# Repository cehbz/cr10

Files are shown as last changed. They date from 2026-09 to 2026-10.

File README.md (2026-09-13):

# CR-10 refurbishment

Notes and firmware for a used 2017 Creality CR-10: 12 V, the original
Creality Melzi board (ATmega1284P, FT232R USB serial, no bootloader as
shipped), stock 12864 display, and an owner-added second power supply
feeding the bed through an external MOSFET module.

## Firmware

The board shipped with Creality's Marlin 1.0.0 build from October 2017. That
build has no thermal runaway protection and no `M112` handler; its published
source is at https://github.com/Creality3DPrinting/CR10-Melzi-1.1.2.

This repo builds Marlin 2.1.2.8 for it.

- `Marlin/` is the upstream Marlin repository as a submodule, pinned to the
  2.1.2.8 tag.
- `config/` is Marlin's own CR-10 example configuration
  (`config/examples/Creality/CR-10/CrealityV1` from the Configurations repo
  at `release-2.1.2.8`) with one change: `EMERGENCY_PARSER` enabled in
  `Configuration_adv.h`, so `M112` is acted on immediately rather than queued.
  Thermal protection for hotend and bed is on in the example config.
- `boot/` is the optiboot bootloader the build assumes; see `boot/README.md`.

Build (needs PlatformIO):

```
git clone --recurse-submodules --shallow-submodules <this repo>
scripts/build.sh
```

The result is `build/firmware.hex`. It uses about 97% of flash and 93% of
RAM, which is normal for Marlin 2 on this processor.

### One-time: bootloader over ISP

Because the board has no bootloader, the first flash goes through the 6-pin
ISP header next to the processor, using an FT232H breakout as the
programmer (avrdude's `ft232h` definition; the FT232H's inputs are 5 V
tolerant, so no level shifting). Pin 1 of the header has a square pad.

```
ISP header            FT232H
1 MISO  2 VCC         AD2 -> pin 1
3 SCK   4 MOSI        AD0 -> pin 3
5 RESET 6 GND         AD1 -> pin 4
                      AD3 -> pin 5
                      GND -> pin 6
```

Pin 2 stays unconnected: the printer's own supply powers the board during
programming. With the printer on and the FT232H plugged in:

```
scripts/isp.sh probe        # expect Device signature = 0x1e9705
scripts/isp.sh backup       # stock flash + EEPROM to backup/ (kept out of git)
scripts/isp.sh bootloader   # erase, fuses, optiboot
```

On macOS, avrdude may need `sudo` to claim the FT232H from Apple's FTDI
driver. After this step the display is blank until firmware is flashed.

### Flashing over USB

With the bootloader in place, every flash is over the printer's USB port:

```
scripts/flash.sh            # PORT=/dev/tty.usbserial-XXXX to override
```

Stock firmware talked at 115200 baud; so does this build. After a reflash
the EEPROM is reset, so PID and E-steps need redoing and saving with `M500`.

## Hardware findings from the checkout

Recorded here because they are the kind of thing the next owner of a
machine like this needs to know.

- Both power supplies had been trimmed off nominal: the mainboard supply to
  14.4 V and the bed supply to 10.8 V. Both reset to 12.0 V with the pot
  next to the terminal strip.
- The external bed MOSFET module was the common clone design: PC817
  optocoupler, HA210N06-marked MOSFET, and a resistor divider on the gate
  that leaves the gate at half the module's supply. On a 24 V machine that
  is 12 V and the part is fully on; on a 12 V machine it is about 6 V and
  the part runs hot. The heatsink reached 100 °C at under 7 A of bed
  current. Replaced with a module that has a transistor stage after the
  optocoupler.
- The bed wires were terminated with fork lugs pushed into the module's
  cage-clamp terminals. The lugs, not the terminals, discoloured and
  reached 140 °C. Cage clamps take ferrules.
- Stock endstops read `open` at rest and `TRIGGERED` pressed, with pullups
  and no inversion, so an unplugged switch is indistinguishable from an
  untriggered one; homing must be verified by pressing each switch by hand
  under `M119` before the first `G28`.
- The stock 1.0.0 firmware drives the bed in bang-bang mode as a 50% duty
  software PWM at about 7.6 Hz, not fully on, so any external module must
  tolerate PWM. Marlin 2 does the same.

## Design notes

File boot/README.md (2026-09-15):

# optiboot for the Melzi ATmega1284P

`optiboot_atmega1284p.hex` is the unmodified 16 MHz, 115200 baud optiboot
build from the Sanguino core:

- https://github.com/Lauszus/Sanguino/blob/master/bootloaders/optiboot/optiboot_atmega1284p.hex
- last changed in commit `60fbbcf5eaa8ee9167051877b00fb02546c1ba97`
- sha256 `83e8bcac3e177aa47b4fdbff8a5da66cb107e762a721093bb444ebcca130ea00`

The hex is linked at byte 0x1FC00, the top 1 KB of flash, so BOOTSZ has to
select a 512-word boot section based there. That makes the fuses lfuse 0xFF
(external crystal), hfuse 0xDC (BOOTSZ=10 plus BOOTRST), efuse 0xFD (brown-out
at 2.7 V), applied by `scripts/isp.sh bootloader`.

Note that Sanguino's `boards.txt` pairs this same hex with hfuse 0xDE, which
selects a 256-word section based at 0x1FE00. That matches neither where the hex
is linked nor that file's own `upload.maximum_size` of 130048, which reserves
1 KB. Burning 0xDE leaves the reset vector pointing at blank flash, so the
bootloader never runs. The Melzi bootloader guides use 0xDC, and Marlin's
`melzi_optiboot` environment reserves the same 1 KB.

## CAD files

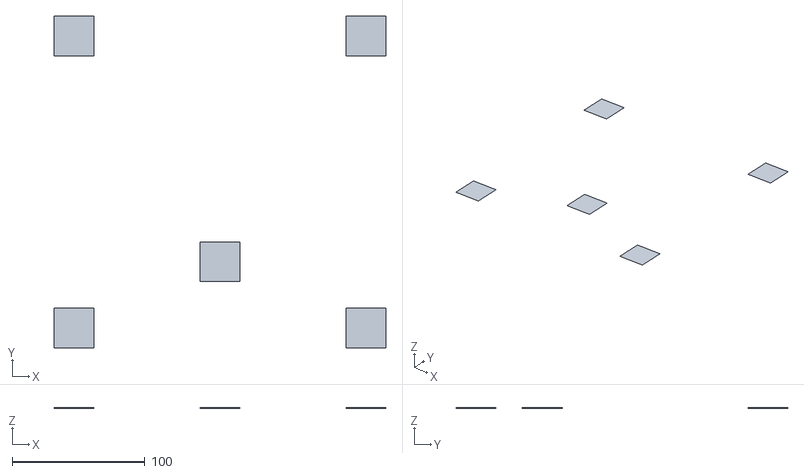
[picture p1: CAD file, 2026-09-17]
models/first_layer_test_offcentre.stl
250.0 x 250.0 x 0.2

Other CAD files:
models/first_layer_test.stl
models/rx100m6-bracket.f3d

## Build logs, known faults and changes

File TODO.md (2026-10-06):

# CR-10 — next session

Machine prints. Filament dried; the storage box sits at ~10 % RH with ~120 g of gel in a
printed tray. Background and measured values: `~/.claude/knowledge/projects/cr10.md`;
history `~/.claude/knowledge/projects/cr10/observations.md`.

## 1. Silent mid-print reboot

Desiccant-box attempt 2: the printer rebooted partway through the first layers with no LCD
message and no USB connected. Marlin shows a message and halts on a thermal fault, and
reports SD errors, so neither fits a silent reboot. Surviving: brownout (the bed's 11–17 A returns
through the negative-to-negative bond between the supplies), watchdog reset (RAM 15296 /
16384 B, a print of thousands of short moves), mains glitch. Not seen since.

If it recurs: start `picocom -b 115200 --imap lfcrlf --logfile <file>
/dev/tty.usbserial-A906UGE8` before the print (opening the port resets the board once,
harmless before a print), start the print from the LCD, leave it logging. The boot banner
after a reboot names the cause: Brown out / Watchdog / Power-Up.

## 2. Bed PSU label

Read the rating on the bed PSU when the case is open, and record it in the observations
log. It was never written down.

## 3. Bed PID tune

Still on Marlin defaults. It holds setpoint, so this is polish. `MAX_BED_POWER` is 255,
so nothing is capping bed duty.

## 4. Corner lift on a long floor

On the next PETG part with a floor of about 200 mm or more, observe whether a corner lifts
at bed 75 with the window closed and the fans off.

## 5. RX100M6 tripod bracket

Fit the print of `models/rx100m6-bracket.stl`. Dry, with the dummy battery in: the door
resting on the slope's end without pinching the cable, the door's hinge arms clearing the
boss, nothing touching the lens or LCD. When the 1/2" button-head screws and 1/4"-20 nuts
arrive: the screw's protrusion, and whether the camera turns on the screw (a lip or a pad if
it does). Design in the KB node, Enclosures for other projects.

## Considered

- Considered, not ordered: textured PEI spring steel with magnetic base, ~฿900, which is the
  right surface for PETG and would end the glass chipping.
- Considered, not started: **24 V on the bed.** The version of the second-PSU mod with a
  real payoff — heat-up in a few minutes rather than ~10, and 80 °C within reach. Two 12 V
  supplies in series into the bed only, external switch stays in the negative leg (the
  clone's PC817 input is isolated, so the stack can float). Not a drop-in: ~37 A full-on on
  this bed, so 10 AWG on the run, a 40 A-class switch (not the MOS25), `MAX_BED_POWER`
  back to ~128 or accept the inrush, and the negative-to-negative bond between the supplies
  has to go. Decide after a few prints whether the heat-up actually bothers you.
- Considered, not ordered: bed insulation mat (cork or foil-faced) under the plate. Cheap,
  no electrical risk, cuts heat-up time and holding duty. Check whether one is already
  fitted before buying.

## Standing

The full-length attended print has happened: the Benchy ran over an hour at bed 75 with
correct polarity and all four module terminations fresh, and nothing in the bed circuit ran
warm. The condition that gated unattended running is discharged. Whether to leave it running
— drying on the bed is hours of bed-only at 60 — is your call, not a rule.

**No bed thermal fuse.** Decided 2026-09-19: not going to fit one, not going to check for
one. The mitigation is attendance, and the one failure of this class that occurred — the
reversed DC input, which heated the bed whenever the machine had power, commanded or not —
was in fact caught that way. Settled; do not re-raise.

The uncommanded heating was a wiring error and is cured, demonstrated rather than assumed:
full supply across the device when commanded off, device at ambient, bed flat. One earlier
observation stays unexplained: 2026-09-11, original module, bed commanded off at 73 and read
77 then 83. That module's input polarity was never observed, so the same reversal would
account for it; the wiring was redone when it was replaced and it cannot now be tested.

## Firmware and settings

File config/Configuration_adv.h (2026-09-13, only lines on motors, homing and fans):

#define E0_AUTO_FAN_PIN -1
#define E1_AUTO_FAN_PIN -1
#define E2_AUTO_FAN_PIN -1
#define E3_AUTO_FAN_PIN -1
#define E4_AUTO_FAN_PIN -1
#define E5_AUTO_FAN_PIN -1
#define E6_AUTO_FAN_PIN -1
#define E7_AUTO_FAN_PIN -1
#define CHAMBER_AUTO_FAN_PIN -1
#define COOLER_AUTO_FAN_PIN -1
#define HOMING_BUMP_MM      { 5, 5, 2 }       // (linear=mm, rotational=°) Backoff from endstops after first bump
#define HOMING_BUMP_DIVISOR { 2, 2, 4 }       // Re-Bump Speed Divisor (Divides the Homing Feedrate)
#define QUICK_HOME                            // If G28 contains XY do a diagonal move first
#define MICROSTEP_MODES { 16, 16, 16, 16, 16, 16 } // [1,2,4,8,16]
#define ADVANCED_PAUSE_FEATURE
  #define ADVANCED_PAUSE_PURGE_FEEDRATE        3  // (mm/s) Extrude feedrate (after loading). Should be slower than load feedrate.
  #define ADVANCED_PAUSE_PURGE_LENGTH         50  // (mm) Length to extrude after loading.
  #define ADVANCED_PAUSE_RESUME_PRIME          0  // (mm) Extra distance to prime nozzle after returning from park.
  #define HOME_BEFORE_FILAMENT_CHANGE             // If needed, home before parking for filament change

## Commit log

2026-09-13 Marlin 2.1.2.8 build and refurbishment notes for a 2017 CR-10
    Pin upstream Marlin as a submodule and carry Marlin's own CR-10 Melzi
    example configuration in config/, with EMERGENCY_PARSER enabled so M112
    acts immediately. Scripts cover the PlatformIO build, the one-time
    optiboot burn over ISP with an FT232H, and USB flashing afterwards.
    The README records what the checkout found: both PSUs trimmed off 12 V,
    the clone bed MOSFET module's half-supply gate divider running hot on a
    12 V machine, fork lugs in cage-clamp terminals, and the stock 1.0.0
    firmware's lack of thermal protection and M112.
    Claude-Session: https://claude.ai/code/se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
    [Configuration.h, Configuration_adv.h]
2026-09-15 Correct the ATmega1284P high fuse to 0xDC
    scripts/isp.sh took its fuse values from Sanguino's boards.txt, which
    pairs hfuse 0xDE with this optiboot hex. That selects a 256-word boot
    section based at 0x1FE00, but the hex is linked at 0x1FC00 and needs a
    512-word section, so the reset vector would have pointed at blank flash
    and the bootloader would never have run.
    Three things agree on 0xDC: where the hex is linked, boards.txt's own
    upload.maximum_size of 130048 reserving 1 KB, and Marlin's melzi_optiboot
    environment reserving the same. Caught before burning; the corrected
    value is what is on the board.
    Claude-Session: https://claude.ai/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
2026-09-17 Add first-layer test models and a handoff TODO
    models/ holds a five-pad single-layer test sized for this bed: 30 mm pads at
    the four tramming points and the centre, which checks level across the whole
    plate rather than wherever the nozzle lands, and keeps each patch of PETG on
    glass small enough to lift without taking glass with it. The offcentre
    variant moves the fifth pad clear of a chip in this plate's glass.
    TODO.md is the handoff: re-terminate the DC IN lugs, which are the only
    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
    [first_layer_test.stl, first_layer_test_offcentre.stl]
2026-09-17 Move the commissioning checklist into the repo, add the bed power question
    The checklist lived in the Obsidian vault for convenience while ticking
    items off. It is now a record rather than a task list, since every line
    carries the measurement that closed it, so it belongs with the project.
    Its three remaining open lines were already covered by TODO.md and have
    been dropped from the record rather than duplicated.
    Adds the bed power question to TODO. The bed measures 1.8 ohms and draws
    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
2026-09-17 Retire the commissioning record to git history
    It exists in the previous commit, which is where it belongs. Current state
    is TODO.md; the checklist was a working surface for ticking items off and
    every line is now closed with the measurement that closed it.
    TODO's pointer changes from a link to the retrieval command, since the file
    is no longer in the tree.
    Claude-Session: https://claude.ai/code/session_01PepV1gnvdCdiknPodU9G6s
2026-09-19 Close the lug item, record the bed power evidence, record the hotend find
    DC IN lugs re-terminated; at 70 all four lugs ~49 within 5 °C, FET 55,
    nothing above 50 through an hour-plus. Motion accuracy retired on the
    user's call; the commissioning checklist is retired as a source.
    Bed power: the one run with the current module and its leads swapped
    (09-17, FET saturated, 11.25 V at the bed) went 46 → 63 °C in ~3:40.
    With assumed thermal mass and still-air losses that is ~150 ± 50 W,
    11–17 A, consistent with the vendor's 220 W / 18 A. The 1.8 Ω DMM
    reading has no recorded lead zeroing or probe location. Earlier
    observations are now each pinned to the module fitted and whether its
    input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
2026-09-19 Close the hotend item; next is the cube
    Tube plug removed, tube end judged fine and left uncut, tube refitted hot
    and bottomed on the nozzle. Three G1 E30 F150 came out gray and glossy
    with a few small bubbles remaining, so the bubbles are carried forward:
    read the filament container's hygrometer before the cube, dry the spool
    if the cube strings. The cube is also the test of the tube-plug
    hypothesis — no black specks in it.
    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
2026-09-20 Benchy done; next is drying the filament and saving the Cura settings
    The Benchy completed with the recessed lettering intact on the fat
    first layer, so those settings go into the profile. The remaining
    defect is stringing and zits, and the filament container read 78 % RH
    after a night sealed, so drying the spool on the bed comes before any
    retraction tuning. Adds the retraction and coasting set to try on the
    dry spool, and the first-layer horizontal expansion for the cases.
    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
2026-09-20 Trim the TODO to open work
    The Cura profile is saved with every override, so the save-the-profile
    item goes; the bed power conclusion lives in the KB node now, so its
    section goes too, leaving only the PSU-label residual. Next item is the
    first case on the dry spool, which is also the judge of the retraction
    and coasting settings.
    Claude-Session: https://claude.ai/code/session_01BiJCtXi6KwHXE8YSFzq2Ju
2026-09-29 Retire the drying item; add the silent reboot and bed-margin items
    The filament is dried and the storage box holds ~10 % RH, so the drying
    item goes. Two failures from the desiccant-box print become open items:
    a silent mid-print reboot with no USB and no LCD message, with the
    surviving hypotheses and the serial-logging capture that separates them
    if it recurs; and the bed margin, a heating failure at 75 and a corner
    lift at 70 on a 215 mm part, with room airflow from two fans as the
    hypothesis covering both and the unfused wall pillars. Prints since with
    the fans off have fused cleanly; the heating failure and the lift are
    not yet re-checked. The first-case item now names the fan controller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
2026-09-29 Close the first-case item; add the snap-post enclosure print
    The fan controller enclosure printed and fitted: lid slightly loose,
    minimal stringing, power opening clean, PCB supports aligned. The item
    that waited on it goes. The snap-post version now printing is the open
    question: at M2.5 each post half is about 0.7 mm, marginal for a 0.4 mm
    nozzle. The bed PSU label residual becomes its own item.
    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
2026-09-30 Close the bed-heating, snap-post and parts items; watch for a long-floor lift
    No bed heating failure since the fans went off and the window closed,
    but no part since has had a floor as long as the one that lifted, so
    that check becomes its own item for the next long part. The snap-post
    enclosure printed; the posts work but the features are too small to be
    practical, so the approach is dropped. The MOS25 and the crimper
    arrived; the clone module stays in service, so nothing is left waiting
    on parts.
    Claude-Session: https://claude.ai/code/session_012AM5wpuZKEEQBsWeDMgsVd
2026-10-06 Add the RX100M6 tripod bracket design
    The bracket mounts the camera on a tripod with the battery door open for a
    dummy battery. A sloped floor lets the sprung door rest about 10 degrees
    open, leaving the cable a 4-7 mm gap, and a boss bears on the tripod-socket
    fixture between the door's hinge arms. The .f3d goes to LFS through
    models/.gitattributes; the STL is derived and stays untracked.
    Claude-Session: https://claude.ai/code/session_015XTAZu726ZFj23QtRzfmen
    [rx100m6-bracket.f3d]
2026-10-06 Add the RX100M6 bracket fit to the TODO
    The first print is checked dry now and with the screws and nuts once
    they arrive; the item lists what each fit has to show.
    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
2026-10-06 Ignore the bracket STL exported from its .f3d
    The STL is derived from models/rx100m6-bracket.f3d, so it stays out of
    the repo; the first-layer test STLs have no other source and stay
    tracked.
    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

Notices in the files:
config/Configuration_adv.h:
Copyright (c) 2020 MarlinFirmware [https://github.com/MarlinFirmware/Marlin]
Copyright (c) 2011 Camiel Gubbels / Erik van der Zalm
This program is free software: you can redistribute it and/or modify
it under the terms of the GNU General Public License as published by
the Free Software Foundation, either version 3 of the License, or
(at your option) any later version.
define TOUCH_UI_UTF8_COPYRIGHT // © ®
